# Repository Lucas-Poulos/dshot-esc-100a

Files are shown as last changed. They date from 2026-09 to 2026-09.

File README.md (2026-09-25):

# dshot-esc-100a

A 12 V, 100 A three-phase **all-N-channel** motor driver for a high-power
drone motor, controllable over **DShot150/300/600/1200**.

| | |
|---|---|
| Battery | 3S LiPo, 9.0–12.6 V (operating range 6–16 V) |
| Continuous | **100 A** (~1.2 kW) |
| Burst | **150 A** for 10 s |
| Bridge | 6 switch positions × **2 paralleled N-channel MOSFETs = 12 total** |
| Gate driver | **DRV8323R** (RS or RH — one footprint, both variants) |
| Controller | **STM32G071CBT6** running **AM32** |
| Control | DShot150/300/600/1200, bidirectional, + ESC telemetry |
| Efficiency | ~98.5 % at 100 A (≈19 W dissipated) |

**Status: schematic complete and ERC-clean (160 components). PCB floorplanned
and DRC-clean — 80 × 68 mm, 4 layers, 2 oz outer. Routing not started.**

---

## Why all N-channel, and how the high side is driven

A P-channel high-side switch is the easy way to build a bridge and the
wrong way here — P-channel parts with usable R_DS(on) at 100 A don't exist
in a sane package. Both rails are N-channel, so the high-side gate has to
be driven above the battery rail.

The DRV8323R does that with an on-chip **charge pump**, not a bootstrap
capacitor. A bootstrap cap must be refreshed by pulling the phase node
low, which caps duty cycle below 100 %. A charge pump holds the gate up
indefinitely, so the high-side FET stays fully enhanced at **100 % duty** —
exactly the regime "drive it hard" lives in.

## Shoot-through: four independent layers

Shoot-through at 12 V into 2 × 0.43 mΩ is roughly **14 kA**, limited only
by parasitics. It destroys the bridge in microseconds and no fuse is fast
enough. So it's prevented four times over, and no single layer is trusted:

| Layer | Mechanism | Independent of |
|---|---|---|
| 1 | TIM1 hardware dead-time generator, **625 ns** | firmware timing bugs |
| 2 | DRV8323R cross-conduction lockout + 100 ns | the MCU entirely |
| 3 | 6 × SN74LVC1G97 combinational interlock | MCU *and* driver |
| 4 | Gate-source pulldowns + per-FET series gate resistors | everything active |
| 0 | `nFAULT` → `TIM1_BKIN` kills all 6 outputs in hardware | firmware latency |

The dead-time budget works out **negative** under nominal conditions —
because sink current is set 3.5× source current, the outgoing FET is
already off before the incoming one conducts. The 625 ns is therefore pure
margin against V_th spread, tempco, and gate ringing. Full derivation from
the FET's measured gate charge: **[`docs/shoot-through.md`](docs/shoot-through.md)**.

## Documentation

| Document | What's in it |
|---|---|
| [`docs/architecture.md`](docs/architecture.md) | topology, block diagram, sheet map, design decisions |
| [`docs/shoot-through.md`](docs/shoot-through.md) | the four layers, dead-time budget, DTG encoding |
| [`docs/power-budget.md`](docs/power-budget.md) | conduction/switching/shunt losses, thermals, why 2 FETs not 3 |
| [`docs/pinout.md`](docs/pinout.md) | full 48-pin MCU map + AM32 hardware group |
| [`docs/gate-driver-config.md`](docs/gate-driver-config.md) | RH vs RS dual build, every register value derived |
| [`docs/layout.md`](docs/layout.md) | stackup, floorplan, and the routing rules — **read before routing** |
| [`docs/references.md`](docs/references.md) | every datasheet and firmware source used |
| [`firmware/README.md`](firmware/README.md) | AM32 target, SPI init, flashing, **bring-up order** |
| [`manufacturing/BOM.md`](manufacturing/BOM.md) | generated from the netlist, real LCSC numbers |
| [`manufacturing/dshot-esc-100a/ISSUES.md`](manufacturing/dshot-esc-100a/ISSUES.md) | 12 open items — read before fabricating |

## Repository layout

```
design/          GENERATED KiCad 10 project — schematic never saved from the GUI
  01_power_in  02_gate_driver  03_power_stage
  04_mcu       05_sense        06_protection
  lib/         DRV8323R + STM32G071CBTx symbols
scripts/        the source of truth for everything in design/
  gen_custom_symbols.py  gen_project.py  wire_sheets.py
  gen_footprints.py      gen_pcb.py      verify_project.py
  gen_bom.py             calc_*.py
  kicad_sch.py           kicad_symlib.py
docs/           design documentation
firmware/       AM32 target + DRV8323RS SPI driver
datasheets/     22 PDFs, synced from LCSC
manufacturing/  BOM, schematic PDF, issue tracker
```

## Reproducing the design

```bash
pgrep -fil kicad                            # must be empty first
python3 scripts/gen_custom_symbols.py       # symbol library
python3 scripts/gen_project.py --verify     # refuses to write if broken
python3 scripts/gen_project.py              # sheets + placement + wiring
python3 scripts/gen_bom.py
python3 scripts/verify_project.py           # the real gate
```

The calculations behind the docs are runnable, not asserted:

```bash
python3 scripts/calc_deadtime.py    # DTG table + dead-time budget
python3 scripts/calc_power.py       # loss and thermal budget
```

## Before you build one

Read [`ISSUES.md`](manufacturing/dshot-esc-100a/ISSUES.md). 11 open, 2
resolved. The ones that still matter most:

- **ESC-001** — the input ripple budget (~50 A RMS) isn't closed.
- **ESC-005** — the shunt needs a Kelvin sense tap in layout; at 0.25 mΩ
  a few mΩ of shared trace is a large error.
- **ESC-012** — 19 W is **not** passively coolable; this design assumes
  forced air.
- **ESC-007** — the buck feedback divider is unverified. Check it before
  first power-on or the MCU may sit outside its supply range.

And follow the bring-up order in `firmware/README.md`. Do not put a motor
on this board first.

## Licence

Hardware: CERN-OHL-S v2. Firmware snippets: MIT, matching AM32.

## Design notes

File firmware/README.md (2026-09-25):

# Firmware — AM32 on this board

This board runs [AM32](https://github.com/am32-firmware/AM32), which is what
makes it DShot-compatible: DShot150/300/600/1200, bidirectional DShot,
and ESC telemetry, all already implemented and field-proven.

Two things are needed on top of stock AM32:

1. **A target definition** (`am32_target.h`) — mechanical, just constants.
2. **A DRV8323RS SPI init** (`drv8323.c`) — AM32 has no SPI gate-driver
   driver at all. Only needed for the **RS** build; an **RH** build runs
   stock AM32 unmodified.

## 1. Target definition

Add the block in `am32_target.h` to AM32's `Inc/targets.h`, and add
`DSHOT_ESC_100A` to the Makefile target list.

Key choices and why:

| Define | Value | Reason |
|---|---|---|
| `HARDWARE_GROUP_G0_A` | — | matches this board's TIM1/COMP2/TIM3 pin map exactly |
| `NO_PA11_PA12_REMAP` | set | **critical.** On the 48-pin G071, PA9/PA10 are dedicated pins 29/32. AM32 remaps PA11/PA12 onto them by default, which is right for 28/32-pin parts and wrong here. Without this the three high-side PWM outputs drive unbonded pads and the motor never spins. The shipping `AIKON_04_G071` target does the same thing. |
| `DEAD_TIME 40` | 625 ns | raw TIM1 `BDTR.DTG`, not nanoseconds. Derived in `docs/shoot-through.md`. |
| `MILLIVOLT_PER_AMP 10` | — | 0.25 mOhm shunt x 40 V/V CSA gain |
| `TARGET_VOLTAGE_DIVIDER 110` | — | 100 k / 10 k = 11:1 (see ESC-011) |

## 2. DRV8323RS SPI init

`drv8323.c` writes the five control registers derived in
`docs/gate-driver-config.md`. It **bit-bangs** SPI rather than using SPI2.

That is a deliberate choice, not a shortcut:

- It is a one-shot transaction at boot plus optional fault polling. There
  is no throughput requirement whatsoever.
- It removes all dependence on the STM32G0 alternate-function table for
  PB10/PB11/PB2, which has **not** been verified against DS12232 (ESC-002).
  Wrong AF number costs a board spin; bit-banging cannot be wrong.
- AM32 has no SPI infrastructure, so hardware SPI would mean adding clock
  enables and init to shared code for zero benefit.

Hardware SPI2 stays available as a later optimisation — the pins were
chosen to be SPI2-capable.

### Call site

In `Src/main.c`, after `initCorePeripherals()` and before the motor is
enabled:

```c
#ifdef USE_DRV8323
    drv8323_init();
#endif
```

### Fault handling

`nFAULT` lands on **PB12 / TIM1_BKIN**. To get the hardware break path,
change AM32's `MX_TIM1_Init()`:

```c
    TIM_BDTRInitStruct.BreakState    = LL_TIM_BREAK_ENABLE;   /* was DISABLE */
    TIM_BDTRInitStruct.BreakPolarity = LL_TIM_BREAK_POLARITY_LOW;
```

With break enabled, a driver fault forces all six outputs inactive in
hardware within one timer clock, with no interrupt and no firmware in the
path. Handling `nFAULT` as a GPIO interrupt instead — which is what most
ESC designs do — costs roughly a microsecond, and a microsecond of
shoot-through at 12 V has already destroyed the bridge.

> This depends on PB12 actually carrying TIM1_BKIN on this package, which
> is **ESC-003 and still unverified**. Until it is confirmed, treat the
> break path as designed-in but unproven, and keep an EXTI fallback.

## Flashing

SWD on `J401` (2x05, 1.27 mm, ARM Cortex Debug pinout) with an ST-LINK:

```bash
# 1. bootloader (once per board)
#    pick the G071 bootloader whose input pin is PB4
# 2. main firmware
make DSHOT_ESC_100A
```

After the bootloader is in, further updates go over the signal wire from a
Betaflight FC or a one-wire USB-serial adapter — no ST-LINK needed.

## Bring-up order

Do not put a motor on this board first.

1. No FETs populated. Confirm 3V3 from the buck, confirm SWD, flash.
2. Still no FETs. Scope `INHx`/`INLx` at the **driver side** of the
   interlock and confirm no overlap, at low and high throttle.
3. Populate FETs. Bench supply **current-limited to 2 A**, no motor.
   Command low throttle; the supply current should stay in the mA range.
   Any jump to the limit is shoot-through — stop.
4. Small motor, no propeller, current-limited supply.
5. Only then the real motor, and only then a propeller.

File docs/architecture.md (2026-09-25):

# Architecture — 12 V / 100 A All-N-Channel Three-Phase Motor Driver

## What this board is

A single-motor brushless ESC (electronic speed controller) for a high-power
12 V drone motor. Six switch positions, each built from **two paralleled
N-channel MOSFETs** (12 FETs total), driven by a **DRV8323R smart gate
driver** with external FETs, commanded by an **STM32G071** running **AM32**
open-source firmware so the board speaks **DShot150/300/600/1200**.

| Parameter | Value | Notes |
|---|---|---|
| Battery | 3S LiPo, 9.0–12.6 V | nominal 11.1 V |
| Operating range | 6–16 V | driver min 6 V; 4S (16.8 V) tolerated |
| Absolute max (silicon) | 40 V FET / 60 V driver | >3x margin on switch-node ringing |
| Continuous current | **100 A** | ~1.2 kW at 12 V |
| Burst current | **150 A**, 10 s | thermally limited, not silicon limited |
| Bridge | 6 positions x 2 FETs = **12 N-channel** | high side AND low side are NMOS |
| PWM frequency | 24 kHz default, 48 kHz option | set in AM32 target |
| Control input | DShot150/300/600/1200, bidirectional | plus telemetry UART |

## Why all-N-channel, and what makes the high side work

A P-channel high-side switch is the easy way to build a bridge, and it is
the wrong way here: P-channel parts with usable R_DS(on) at these currents
do not exist in a sane package. Both rails are N-channel, which means the
high-side gate has to be driven *above* the battery rail.

The DRV8323R solves this with an on-chip **doubler charge pump** rather than
a bootstrap capacitor. That distinction matters for this application:

- A bootstrap cap must be refreshed by pulling the phase node low, so it
  cannot hold the high-side FET on indefinitely — duty cycle is capped
  somewhere below 100%.
- A charge pump holds the gate up forever, so the DRV8323R **supports 100%
  duty cycle**. At full throttle the high-side FET stays fully enhanced,
  which is exactly the regime "drive it very hard" lives in.

The low side is fed from an on-chip low-side linear regulator (VGLS), so
both rails get a clean ~10 V V_GS independent of battery sag.

## Block diagram

```
 XT90 / 8AWG        ┌──────────────── VBAT (12 V) ─────────────────┐
   +12 V ──┬────────┤                                              │
           │    bulk caps                                          │
          GND   3x 330uF polymer        ┌─────────────────┐        │
                + 24x 10uF MLCC         │   DRV8323R      │        │
                                        │  smart gate drv │        │
  ┌──────────────┐   6x PWM   ┌─────────┤  - charge pump  │        │
  │ STM32G071CBU6│───────────▶│interlock│  - VGLS LDO     │        │
  │   (AM32)     │  INHx/INLx │ 6x AND  │  - dead time    │        │
  │              │◀───nFAULT──┤ (74LVC) │  - VDS OCP      │        │
  │ TIM1 + dead  │            └─────────┤  - 3x CSA       │        │
  │ time + BKIN  │◀──SPI (RS variant)───┤  - 600mA buck   │──3V3───┤
  └──────┬───────┘                      └────┬────────────┘        │
         │  COMP2 BEMF                       │ GHx/SHx/GLx         │
         │  + virtual neutral                ▼                     │
         │                     ┌──────────────────────────┐        │
         └─────────────────────┤  12x NMOS, 2 per switch  │        │
    DShot in (PB4) ────────────┤  40 V, 0.85 mOhm         │        │
                               └──────────┬───────────────┘        │
                                          │ A  B  C                │
                                    0.25 mOhm shunt ───────────────┘
                                          │
                                       ┌──▼──┐
                                       │MOTOR│
                                       └─────┘
```

## Sheet map

| Sheet | Block | Key parts |
|---|---|---|
| 01 | Power input & bulk | XT90 pads, reverse-polarity FET, bulk cap bank, TVS |
| 02 | Gate driver | U201 DRV8323R + charge pump / VGLS / buck passives |
| 03 | Power stage | 12x Q3xx MOSFETs, gate networks, shunt, phase pads |
| 04 | MCU | U401 STM32G071CBU6, SWD, DShot input, telemetry |
| 05 | Sense | BEMF dividers, virtual neutral, VBAT divider, NTC |
| 06 | Protection | 6x interlock gates, nFAULT -> TIM1_BKIN, pulldowns |

## Design decisions and the reasoning

**Two FETs per switch, not three.** Two halves conduction loss versus one
while keeping per-position gate charge at ~206 nC, which the DRV8323R charge
pump can still refresh at 48 kHz with margin (see `power-budget.md`). Three
would push the charge pump to its limit and buy less than the first
doubling did.

**40 V FETs on a 12 V bus.** 3S peaks at 12.6 V, but a hard-switched
150 A bridge rings. Parasitic loop inductance of even 5 nH with a 150 A
edge at 100 ns gives V = L·di/dt = 7.5 V of overshoot on top of the rail,
and real layouts do worse. 40 V leaves the part operating at under a third
of its rating.

**Single low-side shunt, three CSAs wired for it.** All three low-side
sources tie to one node; the shunt sits between that node and PGND. CSA A
reads total bus current for AM32 telemetry, CSA B and C are shorted to
PGND. Per-phase VDS overcurrent still works because SHA/SHB/SHC remain
independent. Three separate shunts would buy per-phase FOC current and cost
three times the shunt dissipation — deferred, not designed out.

**Dual-build gate driver.** DRV8323RS (SPI) and DRV8323RH (resistor) are
the same VQFN-48 7x7 pinout with the config pins repurposed. The board
carries both the resistor network and the SPI routing; assembly picks one.
See `docs/gate-driver-config.md`.

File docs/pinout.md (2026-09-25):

# MCU Pinout — STM32G071CBT6 (LQFP-48, 7x7 mm)

## Why this part

AM32 supports the STM32G071. The 48-pin variant is chosen over the more
common 32-pin because it is the only one that frees **PB12 (TIM1_BKIN)**,
which is what makes the hardware fault-break path in `shoot-through.md`
possible, and it leaves a clean SPI bus for the DRV8323RS. It is also
better stocked and *cheaper* than the 32-pin part (LCSC C432212, 3813 in
stock, $2.18 vs C529350 at 424 / $2.54).

Pin numbers below are read from KiCad's own vetted symbol, not transcribed
by hand. KiCad 10 has no `STM32G071CBTx` symbol, but it has
**`STM32G081CBTx`** — the G081CB is the same die and the same package
bonding as the G071CB, differing only by the AES accelerator, and ST
documents both in a single datasheet (**DS12232**). `gen_custom_symbols.py`
copies that symbol into the project library under the correct name.

## AM32 hardware group

`HARDWARE_GROUP_G0_A` + `NO_PA11_PA12_REMAP`.

On the 48-pin package PA9 and PA10 exist as **dedicated** pins 29 and 32,
while pins 33 and 34 are the PA11/PA12 pads that *can* be remapped to
PA9/PA10. AM32 remaps by default (`LL_SYSCFG_EnablePinRemap` in
`Mcu/g071/Src/peripherals.c`), which is right for 28/32-pin parts where
PA9/PA10 are not bonded. Here it is wrong, so the target defines
`NO_PA11_PA12_REMAP` and we wire the dedicated pins 29/32. The shipping
`AIKON_04_G071` target does exactly this, so the path is proven.

## Pin assignment

| Pin | Port | Net | Function |
|---:|---|---|---|
| 1 | PC13 | — | spare |
| 2 | PC14 | — | spare (OSC32_IN) |
| 3 | PC15 | — | spare (OSC32_OUT) |
| 4 | VBAT | +3V3 | tied to VDD |
| 5 | VREF+ | +3V3A | via ferrite + 1 uF \|\| 100 nF |
| 6 | VDD | +3V3 | 100 nF + 4.7 uF |
| 7 | VSS | GND | |
| 8 | PF0 | — | spare |
| 9 | PF1 | — | spare |
| 10 | PF2 | NRST | 100 nF to GND, 10 k pull-up |
| 11 | PA0 | `DRV_nSCS` | SPI chip select (plain GPIO) |
| 12 | PA1 | `ADC_TEMP` | **ADC_IN1** — board temperature |
| 13 | PA2 | `BEMF_C` | **COMP2_INM (IO3)** — phase C back-EMF |
| 14 | PA3 | `V_NEUTRAL` | **COMP2_INP (IO3)** — virtual star point |
| 15 | PA4 | `ADC_BUSV` | **ADC_IN4** — bus voltage divider |
| 16 | PA5 | `LED_DATA` | WS2812 strip (optional) |
| 17 | PA6 | `ADC_CURRENT` | **ADC_IN6** — from DRV8323 SOA |
| 18 | PA7 | `INLC` | **TIM1_CH1N** — phase C low |
| 19 | PB0 | `INLB` | **TIM1_CH2N** — phase B low |
| 20 | PB1 | `INLA` | **TIM1_CH3N** — phase A low |
| 21 | PB2 | `DRV_SDO` | SPI MISO (SPI2_MISO capable) |
| 22 | PB10 | `DRV_SCLK` | SPI SCK (SPI2_SCK capable) |
| 23 | PB11 | `DRV_SDI` | SPI MOSI (SPI2_MOSI capable) |
| 24 | PB12 | `DRV_nFAULT` | **TIM1_BKIN** + EXTI — hardware break |
| 25 | PB13 | `DRV_ENABLE` | GPIO out, 10 k pulldown |
| 26 | PB14 | `DRV_CAL` | GPIO out — CSA auto-calibrate |
| 27 | PB15 | — | spare |
| 28 | PA8 | `INHC` | **TIM1_CH1** — phase C high |
| 29 | PA9 | `INHB` | **TIM1_CH2** — phase B high (dedicated pin) |
| 30 | PC6 | `LED_STATUS` | status LED |
| 31 | PC7 | — | spare |
| 32 | PA10 | `INHA` | **TIM1_CH3** — phase A high (dedicated pin) |
| 33 | PA11 | — | **no connect** (remap disabled) |
| 34 | PA12 | — | **no connect** (remap disabled) |
| 35 | PA13 | `SWDIO` | debug |
| 36 | PA14 | `SWCLK` | debug (also PA14-BOOT0) |
| 37 | PA15 | — | spare |
| 38–41 | PD0–PD3 | — | spare |
| 42 | PB3 | `BEMF_B` | **COMP2_INM (IO1)** — phase B back-EMF |
| 43 | PB4 | `DSHOT_IN` | **TIM3_CH1 + DMA1_CH1** — DShot input |
| 44 | PB5 | — | spare |
| 45 | PB6 | `TELEM` | **USART1 (AF0)** — one-wire telemetry |
| 46 | PB7 | `BEMF_A` | **COMP2_INM (IO2)** — phase A back-EMF |
| 47 | PB8 | — | spare |
| 48 | PB9 | — | spare |

## Sensorless commutation

AM32 runs one comparator (COMP2) and multiplexes its **inverting** input
between the three phase dividers, while the **non-inverting** input sits on
a fixed virtual neutral. Verified against
`Mcu/g071/Src/peripherals.c`, which states the mapping in a comment:

```
PA2   ------> COMP2_INM
PA3   ------> COMP2_INP
```

and `Inc/targets.h`:

```c
#define PHASE_A_COMP LL_COMP_INPUT_MINUS_IO2 // pb7
#define PHASE_B_COMP LL_COMP_INPUT_MINUS_IO1 // pb3
#define PHASE_C_COMP LL_COMP_INPUT_MINUS_IO3 // pa2
```

The virtual neutral is three equal resistors from phase A/B/C tied to a
common node — it synthesises the motor's star point, which is not brought
out on a delta or unterminated wye motor. See sheet 05.

## Open items

> **ESC-002 — SPI alternate-function numbers unverified.** PB10/PB11/PB2
> are the correct *pins* for SPI2 on STM32G0, but the AF index for each
> has not been read out of DS12232 Table 13. This is deliberately not
> load-bearing: AM32 has no SPI driver, so the DRV8323RS configuration
> transfer is **bit-banged** on these pins as plain GPIO. Hardware SPI2 is
> an optimisation to enable later, only after the AF table is checked.

> **ESC-003 — TIM1_BKIN AF on PB12 unverified.** Same situation. The break
> input is a genuine hardware feature and must be confirmed against
> DS12232 before the fault-break path in `shoot-through.md` can be claimed
> as working. If PB12 turns out not to carry TIM1_BKIN, the fallback is
> EXTI on the same pin, which costs interrupt latency (~1 us) instead of
> being instantaneous.

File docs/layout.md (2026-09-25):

# PCB Layout — Stackup, Floorplan, Routing Rules

**Board: 80 × 68 mm, 4 layers, 1.6 mm, 2 oz outer copper.**
Placement is generated by `scripts/gen_pcb.py` and is **DRC-clean at
0 violations** (382 unconnected items is expected — nothing is routed yet).

---

## The one number that matters

Everything else on this board is ordinary. The commutation loop is not:

```
bulk ceramic → high-side FET → phase node → low-side FET → shunt → PGND → ceramic
```

At 150 A with 50 ns edges, `di/dt` = **3 A/ns**. Every 1 nH of loop
inductance adds 3 V of overshoot to a 40 V FET already sitting on a
12.6 V rail.

Loop inductance is set by the distance to the **return plane**, not by
how cleverly the FETs are arranged (`L = μ₀·d·l/w`):

| Return path | `d` | `L_loop` | Overshoot | V_DS peak |
|---|---:|---:|---:|---:|
| High side top / low side bottom | 1.60 mm | 4.36 nH | 13.1 V | 25.7 V |
| All FETs top, return on B.Cu | 1.60 mm | 4.36 nH | 13.1 V | 25.7 V |
| All FETs top, In1 at 0.5 mm (stock 4-layer) | 0.50 mm | 1.36 nH | 4.1 V | 16.7 V |
| **All FETs top, In1 at 0.20 mm (this board)** | **0.20 mm** | **0.54 nH** | **1.6 V** | **14.2 V** |

Splitting high-side and low-side across the board is intuitively
appealing and about **8× worse**, because it forces the return current
through the full board thickness. So: all twelve FETs on F.Cu, with an
unbroken ground plane 0.2 mm beneath them.

## Stackup — tell the fab the 0.2 mm is not negotiable

```
F.Cu     2 oz (70 µm)   DC+ pour, 12 FETs, phase pours, ceramics, shunt, driver
   ──── 0.20 mm prepreg ────   ← the whole trick is this number
In1.Cu   1 oz           SOLID PGND. No splits under the bridge, ever.
   ──── 0.97 mm core ────
In2.Cu   1 oz           gate + sense routing, AGND island under the driver
   ──── 0.20 mm prepreg ────
B.Cu     2 oz (70 µm)   phase lanes to the motor pads, logic, thermal copper
```

A house-standard symmetric 4-layer stack (0.5/0.5/0.5) triples the loop
inductance. If the fab substitutes it, the design has lost most of its
margin.

## Floorplan

```
   0                                                              80 mm
 0 ┌──────────────────────────────────────────────────────────────┐
   │ (o)          ╔══════ DC+ pour ══════════════════════════╗    │
   │  J101 ⊙      ║  24 × 10 µF ceramic, 3 rows              ║    │
   │  VBAT+   C101║  ── directly above the high-side drains ─║    │
15 │  J102 ⊙  C102║  Q301 Q302 │ Q305 Q306 │ Q309 Q310  ← HS ║    │
   │  VBAT-   C103║  ═══ PHASE_A ═══ PHASE_B ═══ PHASE_C ════║    │
30 │  D101 TVS    ║  Q303 Q304 │ Q307 Q308 │ Q311 Q312  ← LS ║    │
   │              ║  RS301..RS304  0.25 mΩ shunt             ║    │
40 │              ╚══════════════════════════════════════════╝    │
   │   gate nets  C201..C208      U201 DRV8323R     L201  R201-211│
55 │              ┌──────────┬──────────┬──────────┐              │
   │              │ PHASE_A  │ PHASE_B  │ PHASE_C  │  lanes on    │
   │ (o)          ⊙ J301     ⊙ J302     ⊙ J303     │  B.Cu        │
68 └──────────────────────────────────────────────────────────────┘
        B.Cu x < 29: MCU, 6 × interlock, headers, decoupling
```

Current flows **down each column**: DC+ → HS drain → HS source → phase →
LS drain → LS source → shunt → PGND. All three columns are identical, so
the three phases commutate the same way. FETs are rotated 90° so the
source/gate edge faces down and the big centre drain pad faces the pour
above it — rotating them the other way makes every phase current double
back on itself and doubles the loop area.

### Layer duties

| Layer | Carries |
|---|---|
| **F.Cu** | DC+ pour, all 12 FETs, phase pours, ceramics, shunt, gate driver, gate networks |
| **In1.Cu** | **Solid PGND.** The return for every commutation loop |
| **In2.Cu** | Gate and sense routing, AGND island under the driver |
| **B.Cu** | Three phase lanes down to the motor terminals, all logic at x < 29, thermal copper |

The three B.Cu phase lanes (x 29.5–38.5, 45.5–54.5, 61.5–70.5, y 22–63)
are kept clear of every part. That is a *routing convenience*, not an
inductance requirement — the motor lead is in series with a 10–100 µH
winding, so its own inductance is irrelevant.

---

## Routing rules, in priority order

1. **Never split In1.Cu under the bridge.** A slot in the return plane
   forces the return current around it and undoes the entire stackup
   argument. No signals on In1 in the bridge area, at all.
2. **Ceramics first, then everything else.** Each 10 µF must reach the
   DC+ pour and drop to In1 through its own via pair, as short as
   possible. These are the loop's high-frequency source; the
   electrolytics are far too slow to participate.
3. **Phase pours: wide enough for 100 A, and no wider.** The phase node
   is the board's dv/dt aggressor. 2 oz copper at 100 A with a 20 °C rise
   needs roughly 20 mm width, or fewer mm plus via stitching to B.Cu.
4. **Shunt sense must be Kelvin (ESC-005).** `SPA`/`SNA` tap the shunt
   pads directly, never the power pour. At 0.25 mΩ, a few mΩ of shared
   trace is a large fractional error.
5. **Gate loops tight and equal.** Route each `GHx`/`GLx` with its return
   (`SHx` for high side, `SHUNT_P` for low side) as a pair. Length
   *mismatch* between phases is not critical — 14 mm of trace is ~84 ps,
   against 625 ns of dead time — but loop *area* is.
6. **Thermal vias under U201.** The stock `_ThermalVias` footprint was
   deliberately **not** used: it embeds 0.2 mm vias and this board is
   2 oz, where 0.3 mm is the realistic fab minimum. Place a 0.3 mm via
   array by hand on the exposed pad.
7. **Keep the phase lanes off the logic.** Already true by placement;
   preserve it when routing.

## Thermals

~19 W at 100 A continuous into 80 × 68 mm is about **0.35 W/cm²** —
better than the 1.1 W/cm² the earlier 50 × 35 mm estimate in
`power-budget.md` assumed, but still **not passively coolable**. The
design assumes propwash or forced air (ESC-012). Bench testing at 100 A
needs a fan.

The shunt is the hottest discrete at 2.5 W; give it copper on both outer
layers and stitch generously.

## Reproducing

```bash
pgrep -fil kicad        # must be empty — the script edits the .kicad_pcb

/Applications/KiCad/KiCad.app/Contents/Frameworks/Python.framework/\
Versions/Current/bin/python3 scripts/gen_pcb.py

kicad-cli pcb drc --output /tmp/drc.rpt --severity-error \
    design/dshot-esc-100a.kicad_pcb        # currently 0 violations
```

`gen_pcb.py` **edits the board in place** so the `(path ...)` linkage from
"Update PCB from Schematic" survives. It also clears and re-adds its own
zones each run — `pcbnew.SaveBoard()` rewrites every UUID, so deduping by
UUID silently accumulated 14 stacked pours before this was caught.

> Once hand-routing starts, stop running `gen_pcb.py`: it re-places every
> footprint. Tracks and hand-drawn zones would survive, but the placement
> they were routed to would not.

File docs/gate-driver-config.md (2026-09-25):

# DRV8323R Configuration — RH and RS Builds

The board is laid out for **both** DRV8323R variants. They are the same
VQFN-48 RGZ package with the same pinout; per datasheet SLVSDJ3D Table 6-4,
**only pins 29-32 differ**:

| Pin | DRV8323**RH** (hardware) | DRV8323**RS** (SPI) |
|---:|---|---|
| 29 | `MODE` | `SDO` |
| 30 | `IDRIVE` | `SDI` |
| 31 | `VDS` | `SCLK` |
| 32 | `GAIN` | `nSCS` |

| | RH | RS |
|---|---|---|
| LCSC | C543035 | C2653553 |
| Stock / price | 2338 / $2.39 | 67 / $4.29 |
| Configured by | resistors R203-R206 | MCU, over SPI |
| Firmware needed | **none** — stock AM32 runs | `drv8323.c` init (supplied) |
| Retuning | swap resistors | change a constant, reflash |

> **Populate exactly one set.** For an RH build fit R203-R206 and leave the
> MCU's SPI pins as inputs. For an RS build **do not fit R203-R206** — a
> 10 k resistor to ground on a live SPI line is a fight the MCU wins, but
> it corrupts logic levels and wastes current. R207 (SDO pull-up) is fitted
> only for RS; SDO is open-drain.

---

## RS build — register values

Derived from SLVSDJ3D Tables 8-15 through 8-19, and from the FET's own
measured gate charge (see `docs/shoot-through.md`). Implemented in
`firmware/drv8323.c`.

### 0x02 Driver Control — `0x080`

| Field | Bits | Value | Why |
|---|---|---|---|
| `PWM_MODE` | 6-5 | `00b` | **6x PWM** — independent high/low per phase, which is what AM32's TIM1 complementary outputs produce |
| `OTW_REP` | 7 | `1b` | report overtemperature warning on `nFAULT` so the break path sees thermal trouble early |
| `DIS_CPUV` | 9 | `0b` | charge-pump undervoltage fault **enabled** |
| `DIS_GDF` | 8 | `0b` | gate-drive fault **enabled** |

### 0x03 Gate Drive HS — `0x39C`

| Field | Bits | Code | Value |
|---|---|---|---|
| `LOCK` | 10-8 | `011b` | unlocked |
| `IDRIVEP_HS` | 7-4 | `1001b` | **330 mA** source |
| `IDRIVEN_HS` | 3-0 | `1100b` | **1140 mA** sink |

### 0x04 Gate Drive LS — `0x79C`

`CBC = 1b`, `TDRIVE = 11b` (4000 ns peak-current window), and the same
`IDRIVEP_LS = 1001b` / `IDRIVEN_LS = 1100b` as the high side.

**Why sink 3.5x harder than source.** Qgd is 12.4 nC per FET, so 24.8 nC
per position. SLVSDJ3D Eq. 11/12 give `IDRIVEP > Qgd/t_r = 248 mA` for a
100 ns rise and `IDRIVEN > Qgd/t_f = 496 mA` for a 50 ns fall. Setting sink
well above that minimum makes turn-off finish before turn-on starts, which
is what drives the dead-time budget negative under nominal conditions.

### 0x05 OCP Control — `0x151`

| Field | Bits | Code | Value |
|---|---|---|---|
| `TRETRY` | 10 | `0b` | 4 ms retry |
| `DEAD_TIME` | 9-8 | `01b` | **100 ns** — a floor beneath TIM1's 625 ns, not an addition to it |
| `OCP_MODE` | 7-6 | `01b` | automatic retry |
| `OCP_DEG` | 5-4 | `01b` | 4 us deglitch |
| `VDS_LVL` | 3-0 | `0001b` | **0.13 V** |

`VDS_LVL` sizing, per SLVSDJ3D Eq. 17 (`V_DS_OCP > I_max * R_DS(on)max`):

```
R_DS(on) hot   = 0.85 mOhm * 1.5      = 1.28 mOhm   (per FET, 125 C)
R per position = 1.28 / 2             = 0.64 mOhm   (two in parallel)
trip current   = 0.13 V / 0.64 mOhm   = 203 A  hot
                 0.13 V / 0.425 mOhm  = 306 A  cold
```

203 A sits above the 150 A burst rating with margin and still catches a
phase-to-phase short long before the FETs do. Raising it to `0010b`
(0.2 V) would push the hot trip to 312 A, which protects almost nothing.

### 0x06 CSA Control — `0x0C3`

| Field | Bits | Code | Value |
|---|---|---|---|
| `CSA_FET` | 10 | `0b` | positive input is `SPx` |
| `VREF_DIV` | 9 | `0b` | **unidirectional** — see below |
| `LS_REF` | 8 | `0b` | low-side VDS measured `SHx` to `SPx` |
| `CSA_GAIN` | 7-6 | `11b` | **40 V/V** |
| `SEN_LVL` | 1-0 | `11b` | 1 V (effectively unused, see below) |

**Unidirectional, not bidirectional.** The default `VREF_DIV = 1b` puts
zero current at VREF/2 = 1.65 V, and AM32 expects a sensor that reads ~0 V
at zero current (`CURRENT_OFFSET` is in millivolts and every shipping
target sets it near 0). Unidirectional also doubles the usable span. The
cost is that regenerative/braking current is no longer measurable —
acceptable for telemetry, and the reason per-phase FOC is listed as a
future change rather than a present capability.

**Scaling with 40 V/V:**

```
R_shunt = 0.25 mOhm  ->  10 mV/A at the ADC
   100 A -> 1.00 V        150 A -> 1.50 V
linear range 0.25 V .. VREF-0.25 V = 3.05 V  ->  saturates at ~305 A
```

So AM32 gets `MILLIVOLT_PER_AMP 10`.

`SEN_LVL` (the shunt overcurrent comparator) would need 1 V across
0.25 mOhm — 4000 A. It can never trip and is left at its default; VDS
overcurrent is the protection that actually does the work here.

---

## RH build — resistor values

`IDRIVE`, `VDS`, `MODE` and `GAIN` are multi-level inputs: the pin is read
as one of 4 or 7 levels set by a resistor to GND (or a tie to GND/VCC).
**The level tables live in SLVSDJ3D Section 8.5 and have not yet been
transcribed** — see issue **ESC-010**. Populating R203-R206 at the
placeholder 10 k shown on sheet 02 will *not* give the settings tabulated
above.

Targets to hit, once the tables are read:

| Pin | Target |
|---|---|
| `MODE` | 6x PWM |
| `IDRIVE` | ~330 mA source / ~1140 mA sink |
| `VDS` | 0.13 V |
| `GAIN` | 40 V/V |

Note the RH part cannot set source and sink independently — one `IDRIVE`
pin sets both. The asymmetry the dead-time budget relies on is therefore
**an RS-only property**. An RH build still has 625 ns of TIM1 dead time
plus the driver's own 100 ns plus the discrete interlock, so it is safe;
it just has less margin than the RS build. This is the strongest technical
argument for populating RS.

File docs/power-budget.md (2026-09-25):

# Power Budget and Thermal Analysis

All numbers are for the worst case the board is specified to: **100 A
continuous, 12.6 V bus, 24 kHz PWM, 120-degree trapezoidal commutation**,
which is what AM32 does. Burst figures use 150 A.

Every calculation here is reproducible with `scripts/calc_power.py`.

## 1. Conduction loss

In 6-step drive two phases conduct and one floats at any instant. Each
switch position therefore conducts for 120 degrees of the 360-degree
electrical cycle — a duty of 1/3 — and carries the full phase current while
it does.

```
I_rms(per position) = I_phase * sqrt(1/3) = 100 * 0.5774 = 57.7 A
I_rms(per FET)      = 57.7 / 2            = 28.9 A      (2 in parallel)
```

R_DS(on) rises with junction temperature. The selected FET is 0.85 mOhm max
at V_GS = 10 V, 25 C; the normalised curve gives roughly 1.5x at 125 C:

```
R_hot        = 0.85 mOhm * 1.5 = 1.28 mOhm
P_cond/FET   = 28.9^2 * 1.28e-3 = 1.07 W
P_cond total = 1.07 * 12         = 12.8 W
```

At 150 A burst this scales as I^2: **28.8 W**.

## 2. Switching loss

AM32 PWMs the high-side switch and runs synchronous rectification on the
low side, so one hard transition pair per PWM period per active position.

```
E_sw  = 0.5 * V_bus * I * (t_r + t_f)
      = 0.5 * 12.6 * 100 * (100ns + 100ns)  = 126 uJ
P_sw  = 126e-6 * 24e3                        = 3.0 W   @ 24 kHz
                                             = 6.0 W   @ 48 kHz
```

This is the number that moves most with the IDRIVE setting — faster edges
cut it, at the cost of more ringing and EMI. It is the main reason the
gate drive strength is made adjustable rather than fixed.

## 3. Shunt loss

```
R_shunt = 0.25 mOhm  (4x 1 mOhm 2512 in parallel, 4 W total rating)
P_shunt = 100^2 * 0.25e-3 = 2.5 W     @ 100 A
        = 150^2 * 0.25e-3 = 5.6 W     @ 150 A
```

Four 2512 parts in parallel spread this over ~50 mm^2 of copper. The shunt
is the single hottest discrete component on the board and wants its own
copper pour on both outer layers.

## 4. Gate drive loss

```
Q_g(per position) = 103 nC * 2 = 206 nC
P_gate = Q_g * V_gs * f_pwm * 6 positions
       = 206e-9 * 10 * 24e3 * 6 = 0.30 W
```

Negligible thermally, but it sets the charge pump requirement below.

## 5. Total and thermal

| Source | 100 A cont | 150 A burst |
|---|---:|---:|
| Conduction (12 FETs) | 12.8 W | 28.8 W |
| Switching @24 kHz | 3.0 W | 4.5 W |
| Shunt | 2.5 W | 5.6 W |
| Gate drive | 0.3 W | 0.3 W |
| Driver + MCU + buck | ~0.6 W | ~0.6 W |
| **Total** | **~19 W** | **~40 W** |

19 W into a 4-layer 2 oz board of roughly 50 x 35 mm is about 1.1 W/cm^2.
That is **not** passively coolable at sane temperatures — this board
assumes propwash or forced air, which is the normal condition for an ESC
mounted on a multirotor. Static bench testing at 100 A needs a fan.

The 150 A figure is explicitly a **10-second burst**: 40 W into the same
copper will climb roughly 40 C above the continuous steady state, so it is
bounded by thermal mass, not by dissipation.

## 6. Charge pump headroom (the constraint on paralleling FETs)

DRV8323 datasheet SLVSDJ3D Eq. 9, trapezoidal commutation:

```
I_VCP  >  Q_g * f_PWM
```

`I_VCP` is at least 15 mA at V_VM = 8 V and higher at 12 V. With two FETs
per position:

```
required @ 24 kHz = 206e-9 * 24e3 =  4.9 mA    -> 3.0x margin
required @ 48 kHz = 206e-9 * 48e3 =  9.9 mA    -> 1.5x margin
```

**This is why the design stops at two FETs per position.** A third would
need 14.8 mA at 48 kHz, leaving effectively no margin against the 15 mA
floor, and the failure mode is not graceful — an under-refreshed high-side
gate comes out of full enhancement and the FET cooks.

## 7. Bulk capacitance

Input ripple current for a three-phase inverter peaks near 50% modulation
at roughly `0.5 * I_dc` RMS, so **~50 A RMS at 100 A** — far beyond any
single part.

| Part | Qty | Role |
|---|---:|---|
| 330 uF 25 V polymer, ~4 A ripple | 3 | bulk, ~12 A ripple total |
| 10 uF 25 V X7R 1210 | 24 | distributed across the bridge, ~1.5 A each |
| 100 nF 50 V X7R 0603 | 6 | one per half-bridge, high-frequency loop |

> **Open item ESC-001.** The polymer bank covers ~12 A of the ~50 A ripple
> budget; the MLCC array is doing most of the work and its effective
> capacitance under DC bias must be verified against vendor curves (a
> 10 uF 25 V X7R 1210 typically derates to 5-6 uF at 12 V). The practical
> mitigation used by every ESC in this class is a **low-ESR capacitor at
> the battery connector on short leads**, because lead inductance, not the
> on-board bank, dominates. Document it as a required accessory rather
> than pretending the board alone handles it.

See DRV8323 datasheet section 10.2 "Bulk Capacitance Sizing".

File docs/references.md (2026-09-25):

# References

Every datasheet fact in this repo traces to one of these. Where a figure is
still assumed rather than read, it carries an `ESC-NNN` issue number.

## Primary datasheets (PDFs in `datasheets/`, manifest in `datasheets/manifest.json`)

| Part | Document | Used for |
|---|---|---|
| **DRV8323R** | TI **SLVSDJ3D** rev D, Mar 2022 — *DRV832x 6-to-60-V Three-Phase Smart Gate Driver* | Table 6-4 (48-pin RGZ pinout, RH vs RS), Figure 9-1 (application circuit), Eq. 9-12 (charge-pump and IDRIVE sizing), Eq. 17 (VDS OCP), Tables 8-15…8-19 (register map), §10.2 (bulk capacitance) |
| **STM32G071CB** | ST **DS12232** — *STM32G071x8/xB* | 48-pin LQFP pinout, alternate-function tables (ESC-002, ESC-003) |
| **STM32G0 series** | ST **RM0444** — reference manual | TIM1 `BDTR.DTG` dead-time encoding, COMP2 input routing, SYSCFG PA11/PA12 remap |
| **TPHR8504PL** | Toshiba — *N-channel 40 V 340 A MOSFET, SOP Advance* | Qg = 103 nC, Qgs1 = 25 nC, Qgd = 12.4 nC, R_DS(on) = 0.85 mΩ max @ V_GS = 10 V |
| **SN74LVC1G97** | TI **SCES416N** rev N, Jan 2017 | Table 1 function table, Figure 6 (`In0` = GND ⇒ `Y = In1 AND NOT In2`), SOT-23 pinout |
| **LMR16006X** | TI **SNVSA13** | buck feedback reference and external component sizing (ESC-007) — the DRV8323R's integrated buck is this converter |
| SMBJ20A | LCSC datasheet | 20 V standoff, 24.5 V breakdown, 32.4 V clamp |
| B5819W | LCSC datasheet | 40 V 1 A Schottky, buck catch diode and gate turn-off bypass |

## Firmware

| Source | Used for |
|---|---|
| [am32-firmware/AM32](https://github.com/am32-firmware/AM32) | DShot implementation, target model |
| `Inc/targets.h` | `HARDWARE_GROUP_G0_A` pin map; `AIKON_04_G071` as the precedent for `NO_PA11_PA12_REMAP` on a 48-pin G071 |
| `Mcu/g071/Src/peripherals.c` | clock tree (HSI 16 MHz → PLL ×8 ÷2 = 64 MHz), `TIM1` init (PSC = 0, CKD = DIV1 ⇒ t_DTS = 15.625 ns), `COMP2` GPIO comment (`PA2 → COMP2_INM`, `PA3 → COMP2_INP`), `LL_SYSCFG_EnablePinRemap` default |
| `Mcu/g071/Src/comparator.c` | phase multiplexing onto one comparator, `LL_COMP_INPUT_PLUS_IO3` as the virtual neutral |
| `Mcu/g071/Src/serial_telemetry.c` | USART1 one-wire telemetry on PB6, AF0, 115200 |
| [AM32 wiki](https://wiki.am32.ca/) | supported MCU list, bootloader/flashing procedure |

## KiCad libraries used

| Item | Source | Note |
|---|---|---|
| `Texas_RGZ0048A_VQFN-48-1EP_7x7mm_P0.5mm_EP5.15x5.15mm_ThermalVias` | KiCad `Package_DFN_QFN` | TI's own RGZ land pattern — exactly the DRV8323R package |
| `PQFN-8-EP_6x5mm_P1.27mm_Generic` | KiCad `Package_DFN_QFN` | its own description lists "Toshiba SOP Advance" among the compatible packages |
| `LQFP-48_7x7mm_P0.5mm` | KiCad `Package_QFP` | STM32G071CBT6 |
| `Transistor_FET:Q_NMOS_SSSGD_AvalancheRated` | KiCad stock | S = pads 1-3, G = 4, D = 5 — matches the PQFN-8 land pattern |
| `74xGxx:74LVC1G97` | KiCad stock | `extends 74LVC1G57`; flattened by `kicad_sch.py::_merge_extends` |
| `MCU_ST_STM32G0:STM32G081CBTx` | KiCad stock | copied and renamed to `STM32G071CBTx` — same die and bonding, DS12232 covers both |

## Design references consulted

- TI **SLVA504** / *Architecture for Brushless-DC Gate Drive Systems* — referenced from SLVSDJ3D §5 for the device-family comparison.
- The four-layer shoot-through argument, the paralleled-FET gate-resistor
  rule, and the charge-pump-limits-parallel-count result are derived in
  `docs/shoot-through.md` and `docs/power-budget.md` from the datasheet
  figures above, not taken from a secondary source.

## A note on one source that was wrong

An automated fetch of the SN74LVC1G97 datasheet returned a pin assignment
(`pin 3 = C, pin 5 = B, pin 6 = VCC`) and a configuration table that
contradicted both KiCad's symbol and the device's own logic diagram — its
"inverter" configuration evaluates to a buffer. Reading the PDF directly
gave `In0 = 3, Y = 4, VCC = 5, In2 = 6` and Table 1 above. **The interlock
in `06_protection.kicad_sch` is wired from the PDF, not the summary.**

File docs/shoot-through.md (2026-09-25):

# Shoot-Through Prevention and Dead Time

Shoot-through is the failure where the high-side and low-side FETs of one
half-bridge are on simultaneously, putting the battery across two FETs with
nothing but their R_DS(on) in the path. At 12 V into 2 x 0.43 mOhm that is
roughly **14 kA**, limited only by parasitic inductance. It destroys the
bridge in microseconds and there is no fuse fast enough. So it is prevented
in four independent layers, no one of which is trusted alone.

---

## Layer 1 — TIM1 hardware dead-time generator (primary)

The STM32G071's advanced timer generates the complementary pair in
**hardware**. Firmware writes one duty value; the timer derives `CHxN` as
the inverse with a guaranteed non-overlap window inserted on both edges.
Because it is a hardware state machine, no firmware bug, interrupt storm,
or stalled loop can make the two outputs overlap.

AM32 sets this through `TIM_BDTRInitStruct.DeadTime = DEAD_TIME`, which is
the **raw DTG[7:0] register value**, not nanoseconds. The conversion is
load-bearing and easy to get wrong, so it is derived here rather than
assumed.

AM32 configures the STM32G071 at `HSI 16 MHz -> PLL(M=1, N=8, R=2) = 64 MHz`,
with `SYSCLK` undivided, `TIM1 Prescaler = 0` and
`ClockDivision = DIV1`. Therefore:

```
t_DTS = 1 / 64 MHz = 15.625 ns
```

With `DTG[7:5] = 0xx` (i.e. DEAD_TIME <= 127) the reference manual gives
`DT = DTG[7:0] x t_DTS`:

| `DEAD_TIME` | Dead time | Duty loss @24 kHz | @48 kHz |
|---:|---:|---:|---:|
| 24 | 375 ns | 0.9 % | 1.8 % |
| 32 | 500 ns | 1.2 % | 2.4 % |
| **40** | **625 ns** | **1.5 %** | **3.0 %** |
| 60 | 938 ns | 2.3 % | 4.5 % |
| 80 | 1250 ns | 3.0 % | 6.0 % |

Above 127 the encoding changes slope, which is why the AM32 `DT160` and
`DT210` targets land at 3.0 us and 6.25 us rather than anything linear.

**This board ships `DEAD_TIME 40` (625 ns).** Justification in the budget
below; `scripts/calc_deadtime.py` regenerates this table.

## The dead-time budget

Dead time must outlast the slowest turn-off, because the *outgoing* FET has
to be fully off before the *incoming* one starts conducting:

```
DT_required  >  t_off(outgoing) - t_on_delay(incoming) + margin
```

For two TPHR8504PL in parallel per position, driven at `IDRIVEN` = 1 A
sink and `IDRIVEP` = 300 mA source. Gate-charge figures are read from the
Toshiba TPHR8504PL datasheet Electrical Characteristics table
(VDD ~20 V, V_GS = 10 V, I_D = 50 A): **Qg = 103 nC, Qgs1 = 25 nC,
Qgd = 12.4 nC** per FET.

| Term | Value | Derivation |
|---|---:|---|
| Driver propagation delay, INx -> Gx | ~100 ns | DRV8323 t_PD (ESC-009) |
| Gate discharge, plateau -> off | (206 - 50) nC / 1 A = 156 ns | 2 x (Qg - Qgs1) |
| **t_off total** | **~256 ns** | |
| Driver propagation delay (incoming) | ~100 ns | cancels against the above |
| Gate charge, 0 V -> plateau | 50 nC / 300 mA = 167 ns | 2 x Qgs1 |
| **t_on_delay total** | **~267 ns** | |
| **Net requirement** | **-11 ns** | |

**The net requirement comes out negative**, and that is the real result,
not a rounding artefact. Because `IDRIVEN` is set 3.3x higher than
`IDRIVEP`, the outgoing FET is already off before the incoming one starts
to conduct, even with zero inserted dead time. Under nominal conditions
this bridge cannot cross-conduct.

So the 625 ns is not covering a nominal overlap — there isn't one. It is
margin against everything that is *not* nominal:

- V_th spread across twelve individual FETs,
- Q_g and R_DS(on) drift over a 150 C junction swing,
- two paralleled gates not switching in unison,
- gate-loop ringing momentarily re-crossing V_th.

625 ns costs 1.5 % of duty at 24 kHz. Buying that much insurance against
a failure that destroys twelve MOSFETs is an easy trade, which is why the
number is not tuned down aggressively.

### Gate-drive current, from the same datasheet numbers

DRV8323 datasheet SLVSDJ3D Eq. 11/12 sizes `IDRIVE` from the **Miller**
charge, not total gate charge:

```
Qgd(position) = 2 x 12.4 nC = 24.8 nC
IDRIVEP > Qgd / t_rise = 24.8 nC / 100 ns = 248 mA   -> set 300 mA
IDRIVEN > Qgd / t_fall = 24.8 nC /  50 ns = 496 mA   -> set 1 A
```

The 1 A sink setting is deliberately above the 496 mA minimum: it is what
produces the turn-off/turn-on asymmetry the budget above relies on.

> Reduce toward `DEAD_TIME 24` (375 ns) only on the bench, with a current
> probe on the DC bus watching for the characteristic shoot-through spike
> at each commutation, and only after the FET and gate-drive settings are
> final.

---

## Layer 2 — DRV8323R internal cross-conduction prevention

The DRV8323R, in 6x PWM mode, independently refuses to turn on one side
while the other is still commanded on, and inserts its own programmable
dead time of **50 / 100 / 200 / 400 ns**. This is a property of the gate
driver silicon and holds even if the MCU commands an illegal state.

Set to **100 ns**. It is deliberately *shorter* than the TIM1 value so the
total dead time stays the deterministic, documented 625 ns rather than the
sum of two uncoordinated delays — the driver's setting acts as a floor for
the case where layer 1 is wrong, not as an addition to it.

- **RS variant:** `DEAD_TIME` bits in the Driver Control register, over SPI.
- **RH variant:** resistor on the `DTC` pin.

---

## Layer 3 — Discrete cross-interlock (sheet 06)

Six **SN74LVC1G97** configurable single-gate logic parts (SOT-23-6, LCSC
C128411) sit between the MCU and the driver inputs.

The '1G97 is a 3-input configurable gate. Its function table (datasheet
SCES416N, Table 1) is a 2-to-1 mux with `In2` as the select:

```
  In2 = L  ->  Y = In1
  In2 = H  ->  Y = In0          i.e.  Y = /In2.In1 + In2.In0
```

TI documents the tie-off we want directly, as **Figure 6, "2-Input AND Gate
With One Inverted Input"**: ground `In0`, and the part becomes
`Y = In1 AND NOT In2`. So:

| Gate | pin 1 `In1` | pin 3 `In0` | pin 6 `In2` | pin 4 `Y` |
|---|---|---|---|---|
| high side | `INHx` from MCU | **GND** | `INLx` from MCU | `INHx` to driver |
| low side | `INLx` from MCU | **GND** | `INHx` from MCU | `INLx` to driver |

```
  INHx_drv = INHx AND NOT INLx
  INLx_drv = INLx AND NOT INHx
```

Both outputs cannot be high simultaneously for any input combination -- it
is combinational, so there is no state to corrupt. Propagation delay is
6.3 ns max at 3.3 V and **identical on both paths**, so it adds no skew and
does not eat into the dead-time budget.

**Is this redundant with layer 2? Largely, yes — and it is here anyway,
for two cases layer 2 does not cover:**

1. **Before the driver is configured.** Between power-on and the point
   where firmware asserts `ENABLE` and writes the SPI registers, the
   DRV8323R's PWM mode is not yet known to be 6x. The interlock is true
   from the instant 3V3 comes up.
2. **A wrong SPI write.** In 3x or 1x PWM mode the `INLx` pins change
   meaning entirely (direction / brake rather than low-side command). A
   firmware bug that selects the wrong mode would silently invalidate
   layer 2's interlock assumption. Layer 3 does not care what mode the
   driver is in.

Each gate has a **0 Ohm bypass link** in parallel so the interlock can be
shorted out for characterisation.

---

## Layer 4 — Gate network and fail-safe biasing (sheet 03)

- **10 kOhm gate-source pulldown on every one of the 12 FETs.** An
  undriven gate is a floating gate, and a floating gate on a 12 V bus with
  dv/dt on the drain will turn a FET on through C_gd. This is the single
  most important passive on the power sheet, and it is what makes the board
  safe during power-up, brown-out, and driver reset.
- **Individual 4.7 Ohm series gate resistor per FET**, not per position.
  Two gates tied directly together form a resonant loop through their own
  package inductance and will oscillate at hundreds of MHz. Separate
  resistors de-Q that loop. This is mandatory for paralleled FETs.
- **Anti-parallel diode across the common gate resistor** (one per
  position, 6 total) so turn-off bypasses the resistor while turn-on does
  not. Turn-off becomes faster than turn-on, which *widens* the effective
  dead time — the asymmetry is in the safe direction.
- **10 kOhm pulldown on all six `INHx`/`INLx` driver inputs**, so a
  tri-stated or unpowered MCU commands "off" rather than "undefined".

---

## Layer 0 — nFAULT into TIM1_BKIN (the fast path out)

Not dead-time related, but the same class of protection and worth stating
plainly: the DRV8323R's **`nFAULT`** output goes to **PB12**, which carries
**TIM1_BKIN**. When the driver detects VDS overcurrent, charge-pump
undervoltage, gate-drive fault or overtemperature, it pulls `nFAULT` low
and the timer's break input forces all six PWM outputs to their inactive
state **in hardware, within one timer clock**, with no interrupt, no
firmware, and no latency.

Firmware then sees the break flag and decides whether to latch off or
retry. Routing a fault to a GPIO and handling it in an ISR — which is what
most ESC designs do — costs about a microsecond, and a microsecond of
shoot-through at 12 V is already fatal.

This requires `BDTRInitStruct.BreakState = LL_TIM_BREAK_ENABLE` in the
firmware patch; AM32's stock G071 init has it **disabled**
(`LL_TIM_BREAK_DISABLE`). See `firmware/README.md`.

> **ESC-003** (in `pinout.md`) tracks confirming that PB12 actually carries
> TIM1_BKIN on this package. Until that is read out of DS12232, layer 0 is
> designed-in but not proven.

---

## Summary

| Layer | Mechanism | Covers | Independent of |
|---|---|---|---|
| 1 | TIM1 DTG, 625 ns | normal commutation | firmware timing bugs |
| 2 | DRV8323R interlock + 100 ns | illegal MCU commands | MCU entirely |
| 3 | 6x 74LVC1G97 | pre-config window, wrong SPI mode | MCU and driver |
| 4 | Gate pulldowns + series R | power-up, brown-out, dv/dt | everything active |
| 0 | nFAULT -> TIM1_BKIN | overcurrent, UVLO, thermal | firmware latency |

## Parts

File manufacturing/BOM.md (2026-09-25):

# Bill of materials

Generated from the schematic netlist by `scripts/gen_bom.py` on 2026-09-25. Do not edit by hand -- regenerate.

**43 distinct lines, 160 placements.** The schematic is fully wired and ERC-clean, so these quantities are real rather than provisional.

Prices and stock are deliberately absent -- they go stale within days. Refresh before a BOM lock with the `lcsc` skill.

---

## Sourcing notes

**The gate driver is the line to watch.** The design is laid out for both DRV8323R variants on one footprint -- only pins 29-32 differ (SLVSDJ3D Table 6-4):

| Part | LCSC | Stock | Price | Configured by |
|---|---|---:|---:|---|
| `DRV8323RSRGZT` | C2653553 | ~67 | $4.29 | SPI, from the MCU |
| `DRV8323RHRGZR` | C543035 | ~2338 | $2.39 | resistors R203-R206 |

RS is the default because it can set source and sink gate current independently, which is what produces the turn-off/turn-on asymmetry the dead-time budget relies on. RH cannot -- one pin sets both. An RH build is still safe but has less margin, and its resistor values are **not yet transcribed** (issue ESC-010). See `docs/gate-driver-config.md` before substituting.

Everything else is commodity: no part below has under ~1000 pieces at LCSC, and the FETs, MCU and logic all have multiple sources.

---

## Lines

| Qty | MPN | LCSC | Value | Package | Refs | Sheets |
|----:|-----|---|---|---|---|---|
| 29 | `FRC0603F1002TS` | `C2906982` | 10k | R_0603_1608Metric | R202, R211, R313, R314, ... (+25) | Gate Driver, MCU, Power Stage, Protection, Sense |
| 26 | `GRM32DR71E106KA12L` | `C77100` | 10u | C_1210_3225Metric | C104, C105, C106, C107, ... (+22) | Gate Driver, Power Input |
| 12 | `FRC0805F4R70TS` | `C2933459` | 4.7 | R_0805_2012Metric | R301, R302, R303, R304, ... (+8) | Power Stage |
| 12 | `TPHR8504PL,L1Q(M` | `C5331611` | TPHR8504PL | PQFN-8-EP_6x5mm_P1.27mm_Generic | Q301, Q302, Q303, Q304, ... (+8) | Power Stage |
| 11 | `CC0603KRX7R9BB104` | `C14663` | 100n | C_0603_1608Metric | C203, C401, C402, C501, ... (+7) | Gate Driver, MCU, Protection, Sense |
| 7 | `B5819W SL` | `C8598` | B5819W | D_SOD-123 | D201, D301, D302, D303, D304, D305, D306 | Gate Driver, Power Stage |
| 6 | `RCA030RLF` | `C22356631` | 0 | R_0603_1608Metric | R325, R326, R327, R328, R329, R330 | Power Stage |
| 6 | `RCA030RLF` | `C22356631` | 0R BYP | R_0603_1608Metric | R601, R602, R603, R604, R605, R606 | Protection |
| 6 | `SN74LVC1G97DBVR` | `C128411` | SN74LVC1G97 | SOT-23-6 | U601, U602, U603, U604, U605, U606 | Protection |
| 5 | `FRC0603F1001TS` | `C2907002` | 1k | R_0603_1608Metric | R402, R504, R505, R506, R510 | MCU, Sense |
| 4 | `HoJLR2512-3W-1mR-1%` | `C2903470` | 1m | R_2512_6332Metric | RS301, RS302, RS303, RS304 | Power Stage |
| 3 | `SPZ1EM331F11O00R` | `C160677` | 330u/25V | CP_Radial_D8.0mm_P3.50mm | C101, C102, C103 | Power Input |
| 2 | `0603WAF1003T5E` | `C25803` | 100k | R_0603_1608Metric | R210, R511 | Gate Driver, Sense |
| 2 | `CL21B475KAFNNNE` | `C98195` | 4.7u | C_0805_2012Metric | C207, C403 | Gate Driver, MCU |
| 1 | `-` | `-` | PHASE_A | SolderWire-2.5sqmm_1x01_D2.4mm_OD3.6mm_Relief | J301 | Power Stage |
| 1 | `-` | `-` | PHASE_B | SolderWire-2.5sqmm_1x01_D2.4mm_OD3.6mm_Relief | J302 | Power Stage |
| 1 | `-` | `-` | PHASE_C | SolderWire-2.5sqmm_1x01_D2.4mm_OD3.6mm_Relief | J303 | Power Stage |
| 1 | `-` | `-` | SWD | PinHeader_2x05_P1.27mm_Vertical | J401 | MCU |
| 1 | `-` | `-` | SIGNAL | PinHeader_1x04_P2.54mm_Vertical | J402 | MCU |
| 1 | `-` | `-` | VBAT+ | SolderWire-2.5sqmm_1x01_D2.4mm_OD3.6mm_Relief | J101 | Power Input |
| 1 | `-` | `-` | VBAT- | SolderWire-2.5sqmm_1x01_D2.4mm_OD3.6mm_Relief | J102 | Power Input |
| 1 | `CC0603KRX7R9BB104` | `C14663` | 100n/16V | C_0603_1608Metric | C205 | Gate Driver |
| 1 | `CC0603KRX7R9BB104` | `C14663` | 100n VREF+ | C_0603_1608Metric | C404 | MCU |
| 1 | `CC0603KRX7R9BB104` | `C14663` | 100n NRST | C_0603_1608Metric | C406 | MCU |
| 1 | `CC0603KRX7R9BB104` | `C14663` | 100n VREF | C_0603_1608Metric | C503 | Sense |
| 1 | `CL10B105KA8NNNC` | `C29936` | 1u/25V | C_0603_1608Metric | C202 | Gate Driver |
| 1 | `CL10B105KA8NNNC` | `C29936` | 1u | C_0603_1608Metric | C208 | Gate Driver |
| 1 | `CL10B105KA8NNNC` | `C29936` | 1u VREF+ | C_0603_1608Metric | C405 | MCU |
| 1 | `CL10B473KB8NNNC` | `C1622` | 47n/50V | C_0603_1608Metric | C201 | Gate Driver |
| 1 | `DRV8323RSRGZT` | `C2653553` | DRV8323RS | Texas_RGZ0048A_VQFN-48-1EP_7x7mm_P0.5mm_EP5.15x5.15mm_ThermalVias | U201 | Gate Driver |
| 1 | `FRC0603F1002TS` | `C2906982` | IDRIVE | R_0603_1608Metric | R203 | Gate Driver |
| 1 | `FRC0603F1002TS` | `C2906982` | VDS | R_0603_1608Metric | R204 | Gate Driver |
| 1 | `FRC0603F1002TS` | `C2906982` | MODE | R_0603_1608Metric | R205 | Gate Driver |
| 1 | `FRC0603F1002TS` | `C2906982` | GAIN | R_0603_1608Metric | R206 | Gate Driver |
| 1 | `FRC0603F1002TS` | `C2906982` | 10k SDO | R_0603_1608Metric | R207 | Gate Driver |
| 1 | `FRC0603F1002TS` | `C2906982` | 10k nFAULT | R_0603_1608Metric | R208 | Gate Driver |
| 1 | `FRC0603F1002TS` | `C2906982` | 10k EN pd | R_0603_1608Metric | R209 | Gate Driver |
| 1 | `FRC0603F3322TS` | `C2933200` | 33.2k | R_0603_1608Metric | R201 | Gate Driver |
| 1 | `NCP18XH103F03RB` | `C13564` | 10k NTC | R_0603_1608Metric | R513 | Sense |
| 1 | `SLS6D38S330MTT` | `C364136` | 33u | L_7.3x7.3_H3.5 | L201 | Gate Driver |
| 1 | `SMBJ20A` | `C364296` | SMBJ20A | D_SMB | D101 | Power Input |
| 1 | `STM32G071CBT6` | `C432212` | STM32G071CBT6 | LQFP-48_7x7mm_P0.5mm | U401 | MCU |
| 1 | `XL-1608UGC-04` | `C965804` | green | LED_0603_1608Metric | D401 | MCU |

---

## Lines needing attention

| MPN | Note |
|---|---|
| `GRM32DR71E106KA12L` | 24 off. Derates to ~5-6 uF at 12 V bias - ESC-001 |
| `TPHR8504PL,L1Q(M` | 12 off, 2 per switch position. 40 V on a 12.6 V bus is deliberate - see docs/architecture.md |
| `SN74LVC1G97DBVR` | Shoot-through interlock. Wired per SCES416N Fig 6 |
| `HoJLR2512-3W-1mR-1%` | 4 in parallel = 0.25 mOhm. Needs a Kelvin sense tap in layout - ESC-005 |
| `SPZ1EM331F11O00R` | Through-hole radial. ~2.8 A ripple each - ESC-001 |
| `DRV8323RSRGZT` | SPI variant. RH (C543035) is pin-compatible - see docs/gate-driver-config.md before substituting |
| `STM32G071CBT6` | 48-pin part is REQUIRED: it is the only one that frees PB12/TIM1_BKIN. Symbol is KiCad's G081CBTx renamed |

## Before ordering

1. Wire the schematic -- quantities here are pre-wiring estimates.
2. Refresh stock for every line; flag anything under 10x requirement.
3. Record a second-source C-number for each thin line in that part's `manufacturing/parts/{Vendor}/{MPN}/{MPN}.md`.
4. Resolve everything in `manufacturing/stm32mp157-devkit/ISSUES.md` or defer it explicitly.
5. Re-run `python3 scripts/verify_project.py`.
6. Re-check stock immediately before placing the order -- do not order against numbers from a previous session.

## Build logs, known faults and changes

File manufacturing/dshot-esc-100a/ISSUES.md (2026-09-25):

# Board Issues — dshot-esc-100a

Open items. Each one is something that is **assumed rather than verified**,
or a decision deliberately deferred. Nothing here is a known-bad design;
they are the places where a second pass is required before fabrication.

Status: `OPEN` | `RESOLVED` | `WONTFIX`

---

## ESC-001 — Input ripple current budget is not closed  ·  OPEN  ·  high

A three-phase inverter's input ripple peaks near `0.5 × I_dc` RMS, so
**~50 A RMS at 100 A**. The on-board bank covers:

- 3 × 330 µF polymer @ ~2.8 A ripple each = **8.4 A**
- 24 × 10 µF X7R 1210 @ ~1.5-2 A each = **36-48 A**

Two things are unverified. First, the MLCC ripple figure is a rule of
thumb, not a vendor number. Second, a 10 µF 25 V X7R 1210 typically
derates to 5-6 µF at 12 V DC bias, so the array's *effective* capacitance
is roughly half its nameplate.

**Action:** pull vendor DC-bias and ripple curves for the exact MPNs
(C77100 / C160677) and recompute. Regardless of outcome, the mitigation
every ESC in this class uses is a **low-ESR capacitor at the battery
connector on short leads** — lead inductance dominates, not the on-board
bank. Document it as a required accessory.

## ESC-002 — SPI alternate-function numbers unverified  ·  OPEN  ·  low

PB10/PB11/PB2 are the correct *pins* for SPI2 on STM32G0, but the AF index
for each has not been read out of DS12232 Table 13.

**Mitigated by design:** `firmware/drv8323.c` bit-bangs SPI as plain GPIO,
so nothing depends on the AF table. Hardware SPI2 is an optimisation to
enable only after the table is checked.

## ESC-003 — TIM1_BKIN on PB12 unverified  ·  OPEN  ·  medium

The hardware fault-break path (`nFAULT` → `TIM1_BKIN` → all six outputs
forced inactive with no firmware involved) assumes PB12 carries TIM1_BKIN
on this package. Not yet confirmed against DS12232.

**Fallback if wrong:** EXTI on the same pin. Costs ~1 µs of interrupt
latency instead of being instantaneous. The board is still protected by
dead-time layers 1-4; only layer 0 degrades.

## ESC-004 — High-current terminals  ·  RESOLVED  ·  2026-09-25

The placeholder `SolderWire-2.5sqmm` footprint was good for ~25 A and its
strain-relief tail was 25 mm long, which made it unplaceable.

Replaced with `dshot-esc-100a:HighCurrentTerminal_8AWG`
(`scripts/gen_footprints.py`): a 3.6 mm plated hole for 8 AWG conductor
(3.26 mm) with a 9 mm annular pad on **both** outer layers, solder mask
pulled back so the joint can be flooded. ~50 mm² of copper per terminal
spreading into the pour.

Applied to `J101`, `J102`, `J301-J303` in the schematic, the parts
catalogue and the PCB.

## ESC-013 — 2 oz copper vs the driver's thermal-via footprint  ·  RESOLVED  ·  2026-09-25

KiCad's `..._ThermalVias` variant of the DRV8323R land pattern embeds
0.2 mm vias. This board is 2 oz outer copper, where 0.3 mm is the
realistic fab minimum, and DRC flagged 25 `drill_out_of_range` errors.

Switched to the plain `Texas_RGZ0048A_VQFN-48-1EP_7x7mm_P0.5mm_EP5.15x5.15mm`
land pattern. A 0.3 mm thermal via array gets placed by hand during
routing — see `docs/layout.md` rule 6.

## ESC-005 — Shunt Kelvin connection not yet expressed  ·  OPEN  ·  medium

`SPA`/`SNA` connect to the shunt node by name. At 0.25 mΩ, a few
milliohms of trace resistance in the sense path is a large fractional
error, so the sense pins must tap the shunt pads directly as a Kelvin
connection rather than joining the power pour.

Schematic-level nets are correct; this is a **layout constraint** to
encode in the design rules. Blocks the PCB pass, not the schematic.

## ESC-006 — No reverse-polarity protection  ·  OPEN  ·  by design

Deliberately omitted. An ideal-diode FET stage at 100 A adds ~0.5 mΩ
(~5 W) plus its own gate drive and a second failure mode. Mitigation is
the polarised XT90 connector.

**Revisit if** this board is ever used somewhere the connector cannot be
relied on.

## ESC-007 — Buck feedback divider unverified  ·  OPEN  ·  medium

`R201`/`R202` = 33.2 k / 10 k assumes a 0.765 V feedback reference,
giving `0.765 × (1 + 3.32) = 3.30 V`. The DRV8323R's integrated buck is an
LMR16006X, but the reference voltage has not been read out of SNVSA13. The
33 µH inductor and 10 µF output cap are likewise from the general LMR16006
application, not a worked calculation for this operating point.

**Consequence if wrong:** the 3V3 rail is off-target and the MCU may sit
outside 1.71-3.6 V. Check before first power-on.

## ESC-008 — VREF+ has no ferrite  ·  OPEN  ·  low

`U401` pin 5 (`VREF+`) ties straight to 3V3 with 1 µF ‖ 100 nF. Good
practice on a board switching 100 A is a ferrite bead between 3V3 and
VREF+. The ADC reads bus voltage, current and temperature — all slow — so
the impact is small, but it is nearly free to add.

## ESC-009 — DRV8323 propagation delay assumed  ·  OPEN  ·  low

The dead-time budget uses `t_PD ≈ 100 ns` for INx → GHx/GLx. Not yet read
from SLVSDJ3D §7.5. It **cancels to first order** between the turn-on and
turn-off paths, so the budget is insensitive to it; this is tidiness.

## ESC-010 — RH resistor values not transcribed  ·  OPEN  ·  medium

`R203-R206` are placeholder 10 k. The real values come from the 4- and
7-level input tables in SLVSDJ3D §8.5, which have not been transcribed.
**An RH build populated as-drawn will not have the intended IDRIVE, VDS,
MODE or GAIN settings.**

Blocks an RH build only. An RS build ignores these (they are DNP) and is
fully specified in `docs/gate-driver-config.md`.

## ESC-011 — `TARGET_VOLTAGE_DIVIDER` scaling unverified  ·  OPEN  ·  low

Set to 110 for the 100 k / 10 k (11:1) divider, on the assumption that
AM32's constant is `ratio × 10`. Shipping targets use 110 and 210, which
is consistent, but the formula has not been read out of AM32's ADC code.

**Consequence if wrong:** reported battery voltage is scaled wrong, and
low-voltage cutoff triggers at the wrong point. Cosmetic on the bench,
potentially damaging to a LiPo in flight.

## ESC-012 — Thermal design is stated, not simulated  ·  OPEN  ·  medium

`docs/power-budget.md` puts ~19 W at 100 A continuous into the board. The
outline is now fixed at **80 × 68 mm**, which is 0.35 W/cm² rather than
the 1.1 W/cm² the original 50 × 35 mm estimate assumed — better, but
still **not passively coolable**; the design assumes propwash or forced
air.

No thermal simulation has been run and no copper area has been sized. The
150 A figure is a 10-second burst bounded by thermal mass, not a steady
state. Blocks the PCB pass.

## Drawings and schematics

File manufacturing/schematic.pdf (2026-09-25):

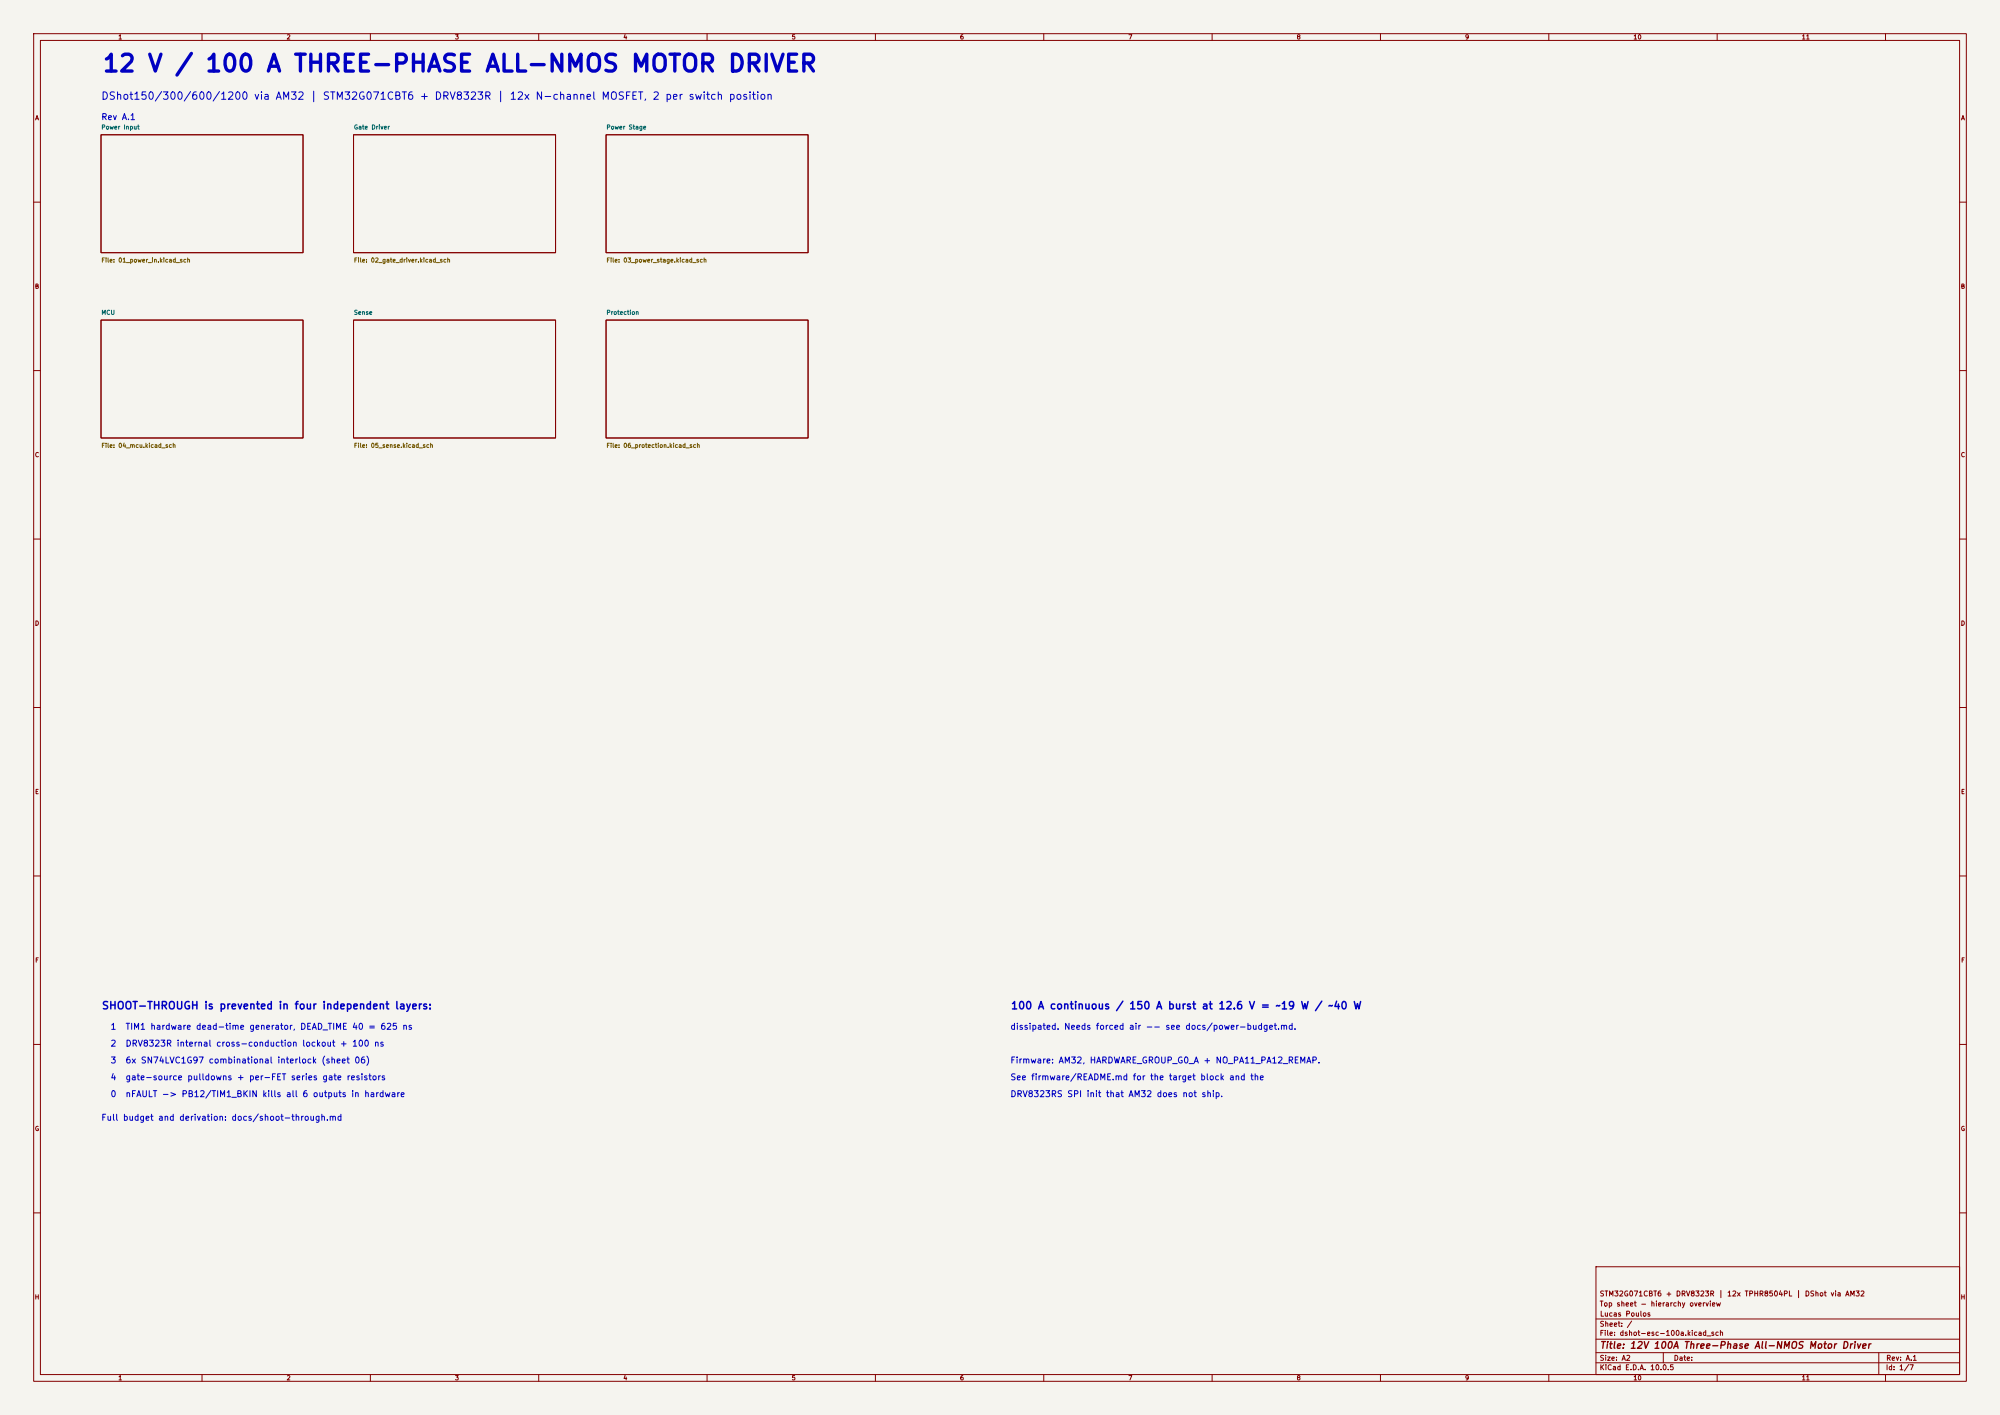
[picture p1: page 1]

12 V / 100 A THREE-PHASE ALL-NMOS MOTOR DRIVER
Power Input File: 01_power_in.kicad_sch MCU

DShot150/300/600/1200 via AM32 | STM32G071CBT6 + DRV8323R | 12x N-channel MOSFET, 2 per switch position

SHOOT-THROUGH is prevented in four independent layers:

dissipated. Needs forced air -- see docs/power-budget.md.

2 DRV8323R internal cross-conduction lockout + 100 ns 3 6x SN74LVC1G97 combinational interlock (sheet 06)

Firmware: AM32, HARDWARE_GROUP_G0_A + NO_PA11_PA12_REMAP.
See firmware/README.md for the target block and the

4 gate-source pulldowns + per-FET series gate resistors
0 nFAULT -> PB12/TIM1_BKIN kills all 6 outputs in hardware

DRV8323RS SPI init that AM32 does not ship.

Full budget and derivation: docs/shoot-through.md

STM32G071CBT6 + DRV8323R | 12x TPHR8504PL | DShot via AM32
Top sheet - hierarchy overview
Lucas Poulos
Sheet: /
File: dshot-esc-100a.kicad_sch
Title: 12V 100A Three-Phase All-NMOS Motor Driver

Size: A2 | Rev: A.1
KiCad E.D.A. 10.0.5 | Id: 1/7

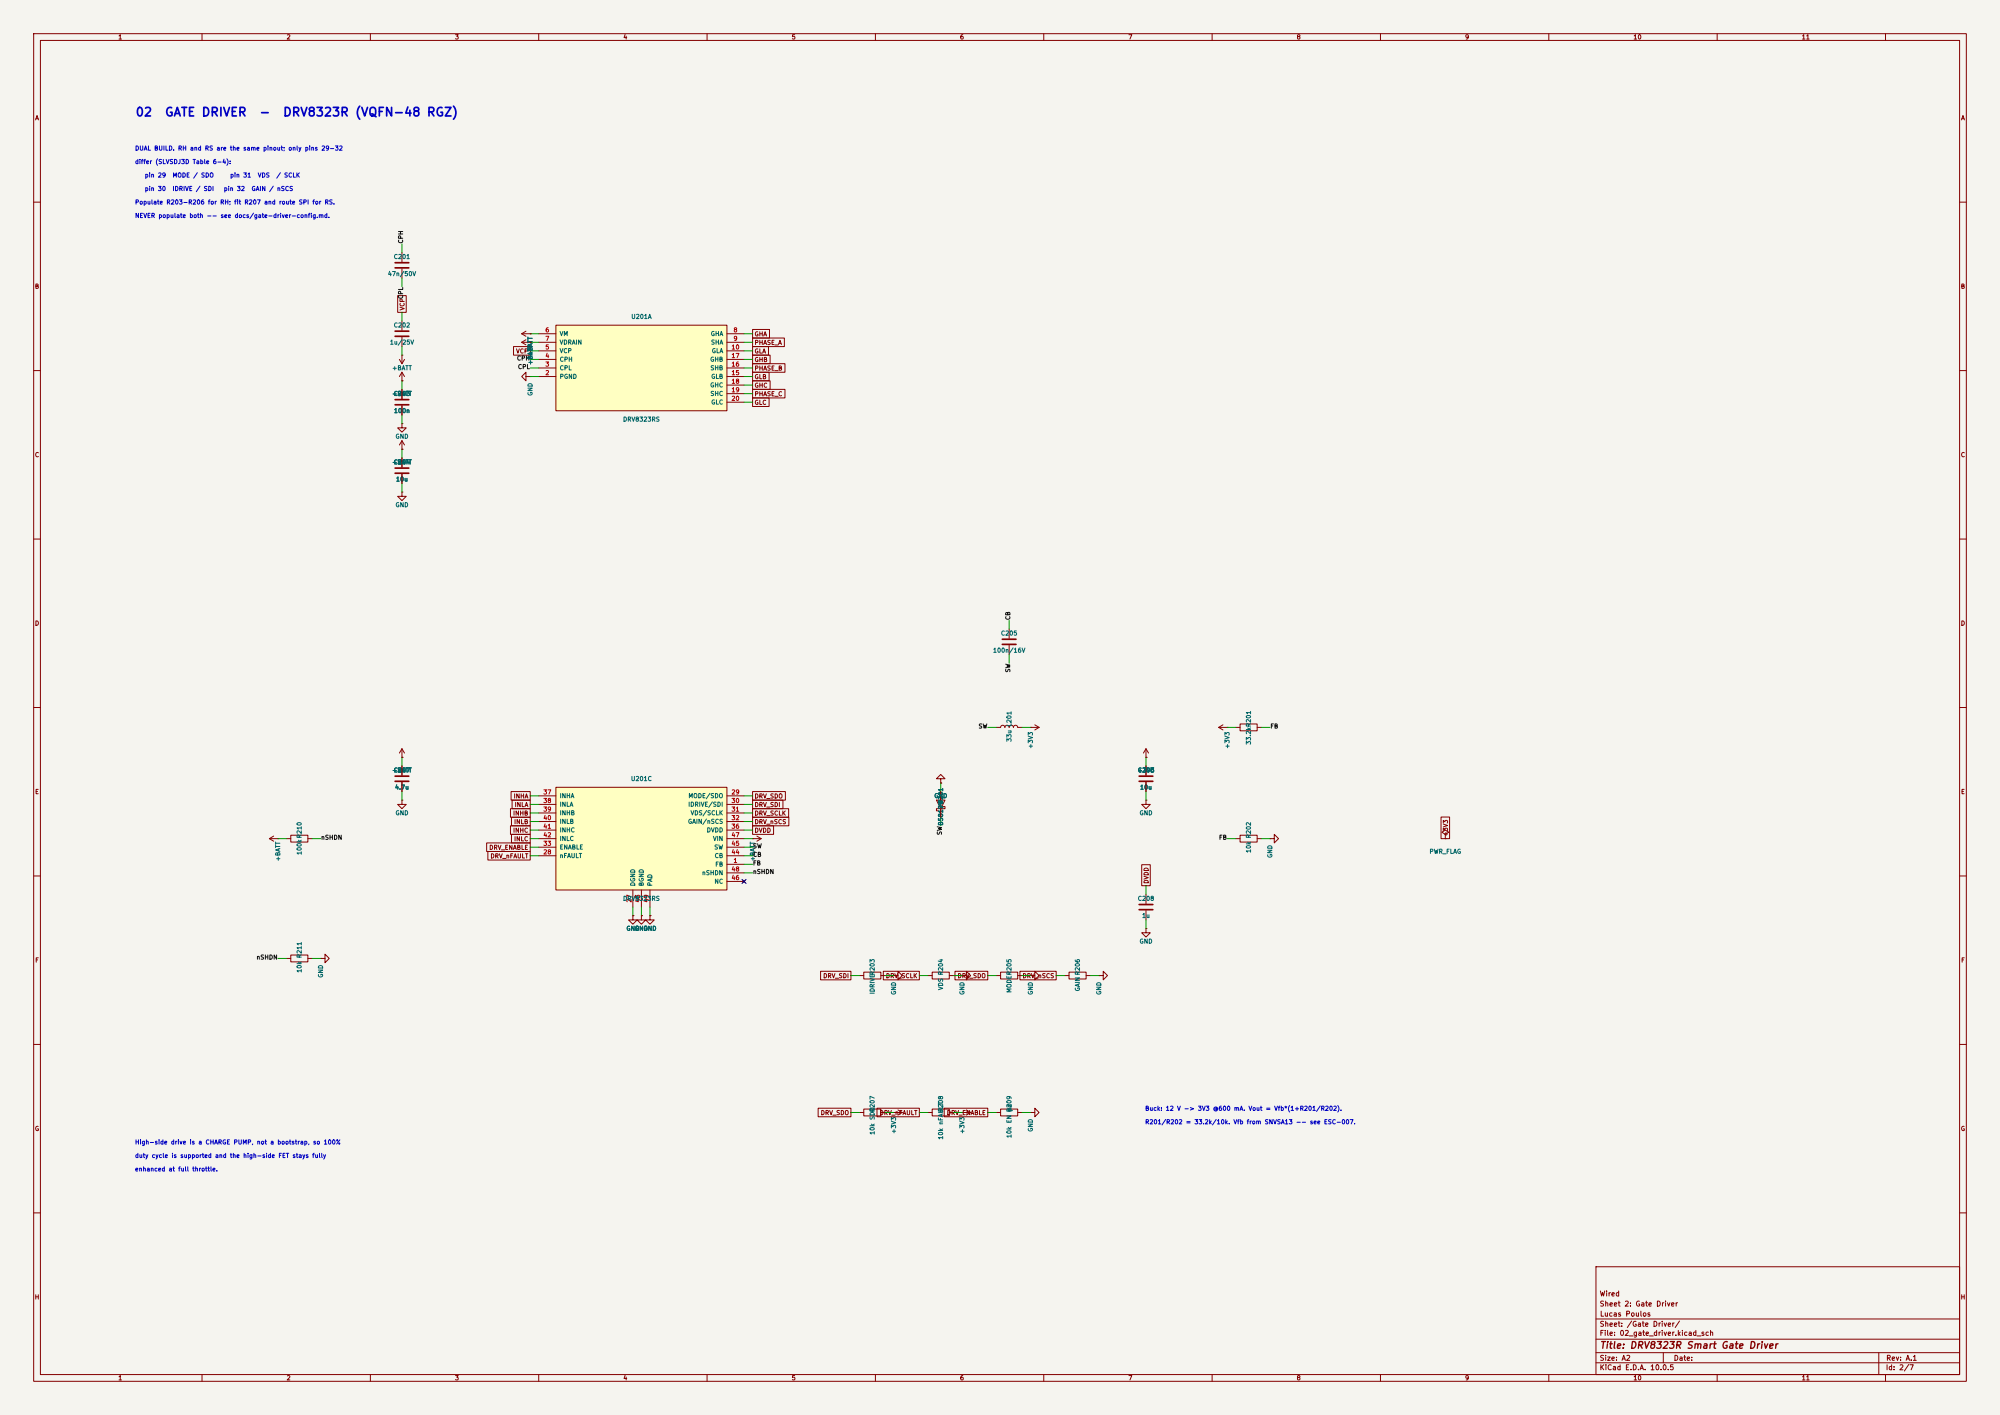
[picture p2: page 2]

differ (SLVSDJ3D Table 6-4): DUAL BUILD. RH and RS are the same pinout; only pins 29-32 02 GATE DRIVER - DRV8323R (VQFN-48 RGZ)

Buck: 12 V -> 3V3 @600 mA. Vout = Vfb*(1+R201/R202).

R201/R202 = 33.2k/10k. Vfb from SNVSA13 -- see ESC-007.

enhanced at full throttle. High-side drive is a CHARGE PUMP, not a bootstrap, so 100%

duty cycle is supported and the high-side FET stays fully

Sheet: /Gate Driver/
File: 02_gate_driver.kicad_sch
Title: DRV8323R Smart Gate Driver

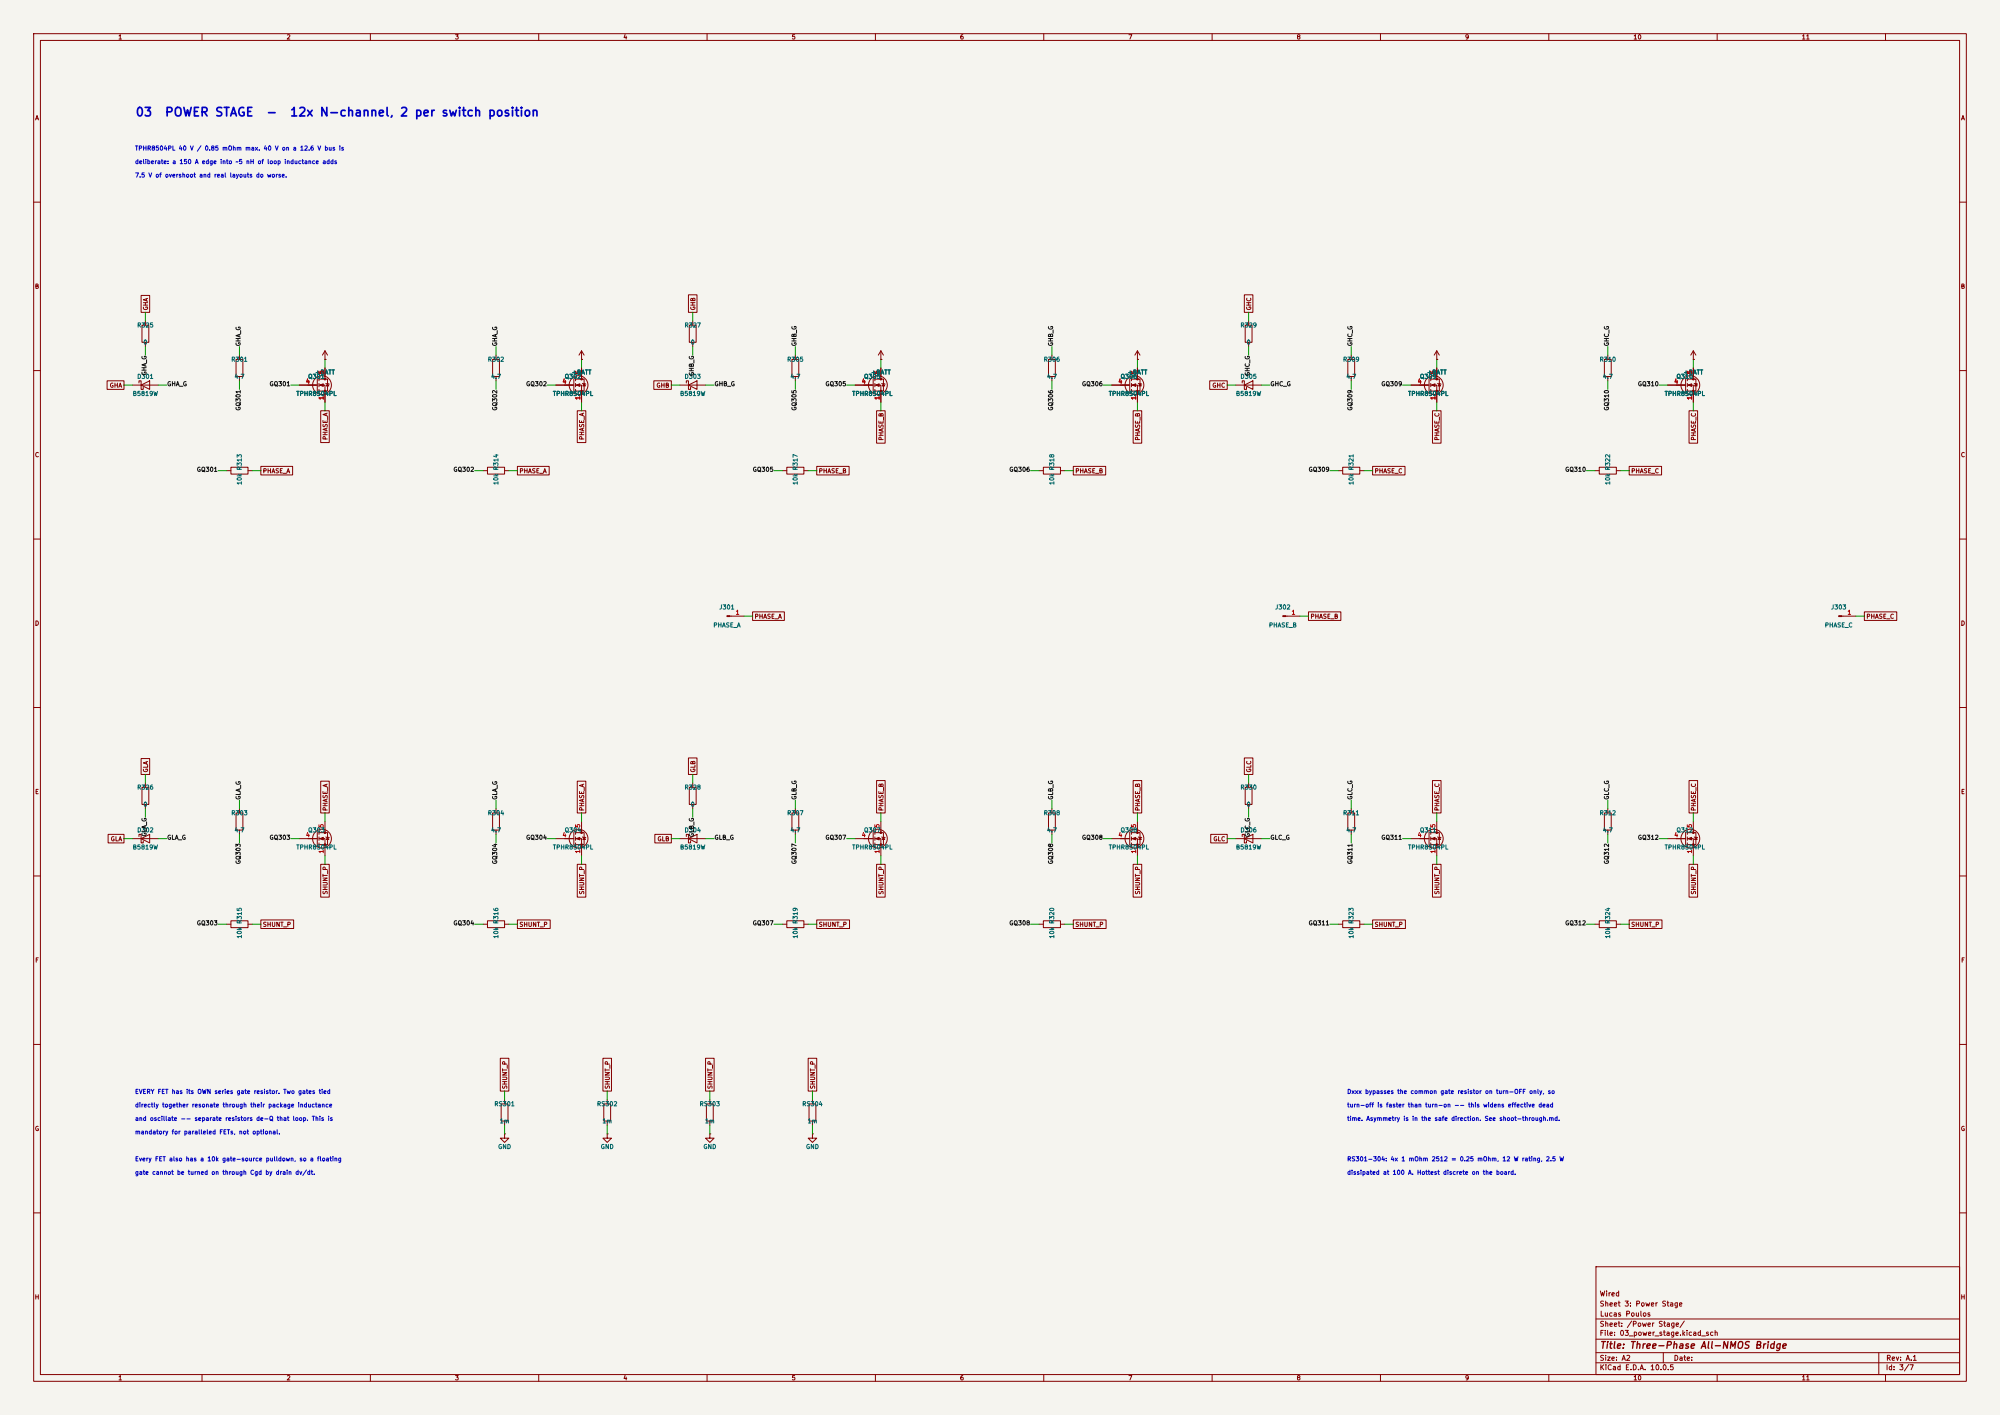
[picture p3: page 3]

03 POWER STAGE - 12x N-channel, 2 per switch position

TPHR8504PL 40 V / 0.85 mOhm max. 40 V on a 12.6 V bus is

deliberate: a 150 A edge into ~5 nH of loop inductance adds

7.5 V of overshoot and real layouts do worse.

directly together resonate through their package inductance EVERY FET has its OWN series gate resistor. Two gates tied

Dxxx bypasses the common gate resistor on turn-OFF only, so

turn-off is faster than turn-on -- this widens effective dead

and oscillate -- separate resistors de-Q that loop. This is gate cannot be turned on through Cgd by drain dv/dt.

time. Asymmetry is in the safe direction. See shoot-through.md.

mandatory for paralleled FETs, not optional.

Every FET also has a 10k gate-source pulldown, so a floating

dissipated at 100 A. Hottest discrete on the board. RS301-304: 4x 1 mOhm 2512 = 0.25 mOhm, 12 W rating, 2.5 W

Sheet: /Power Stage/
File: 03_power_stage.kicad_sch
Title: Three-Phase All-NMOS Bridge

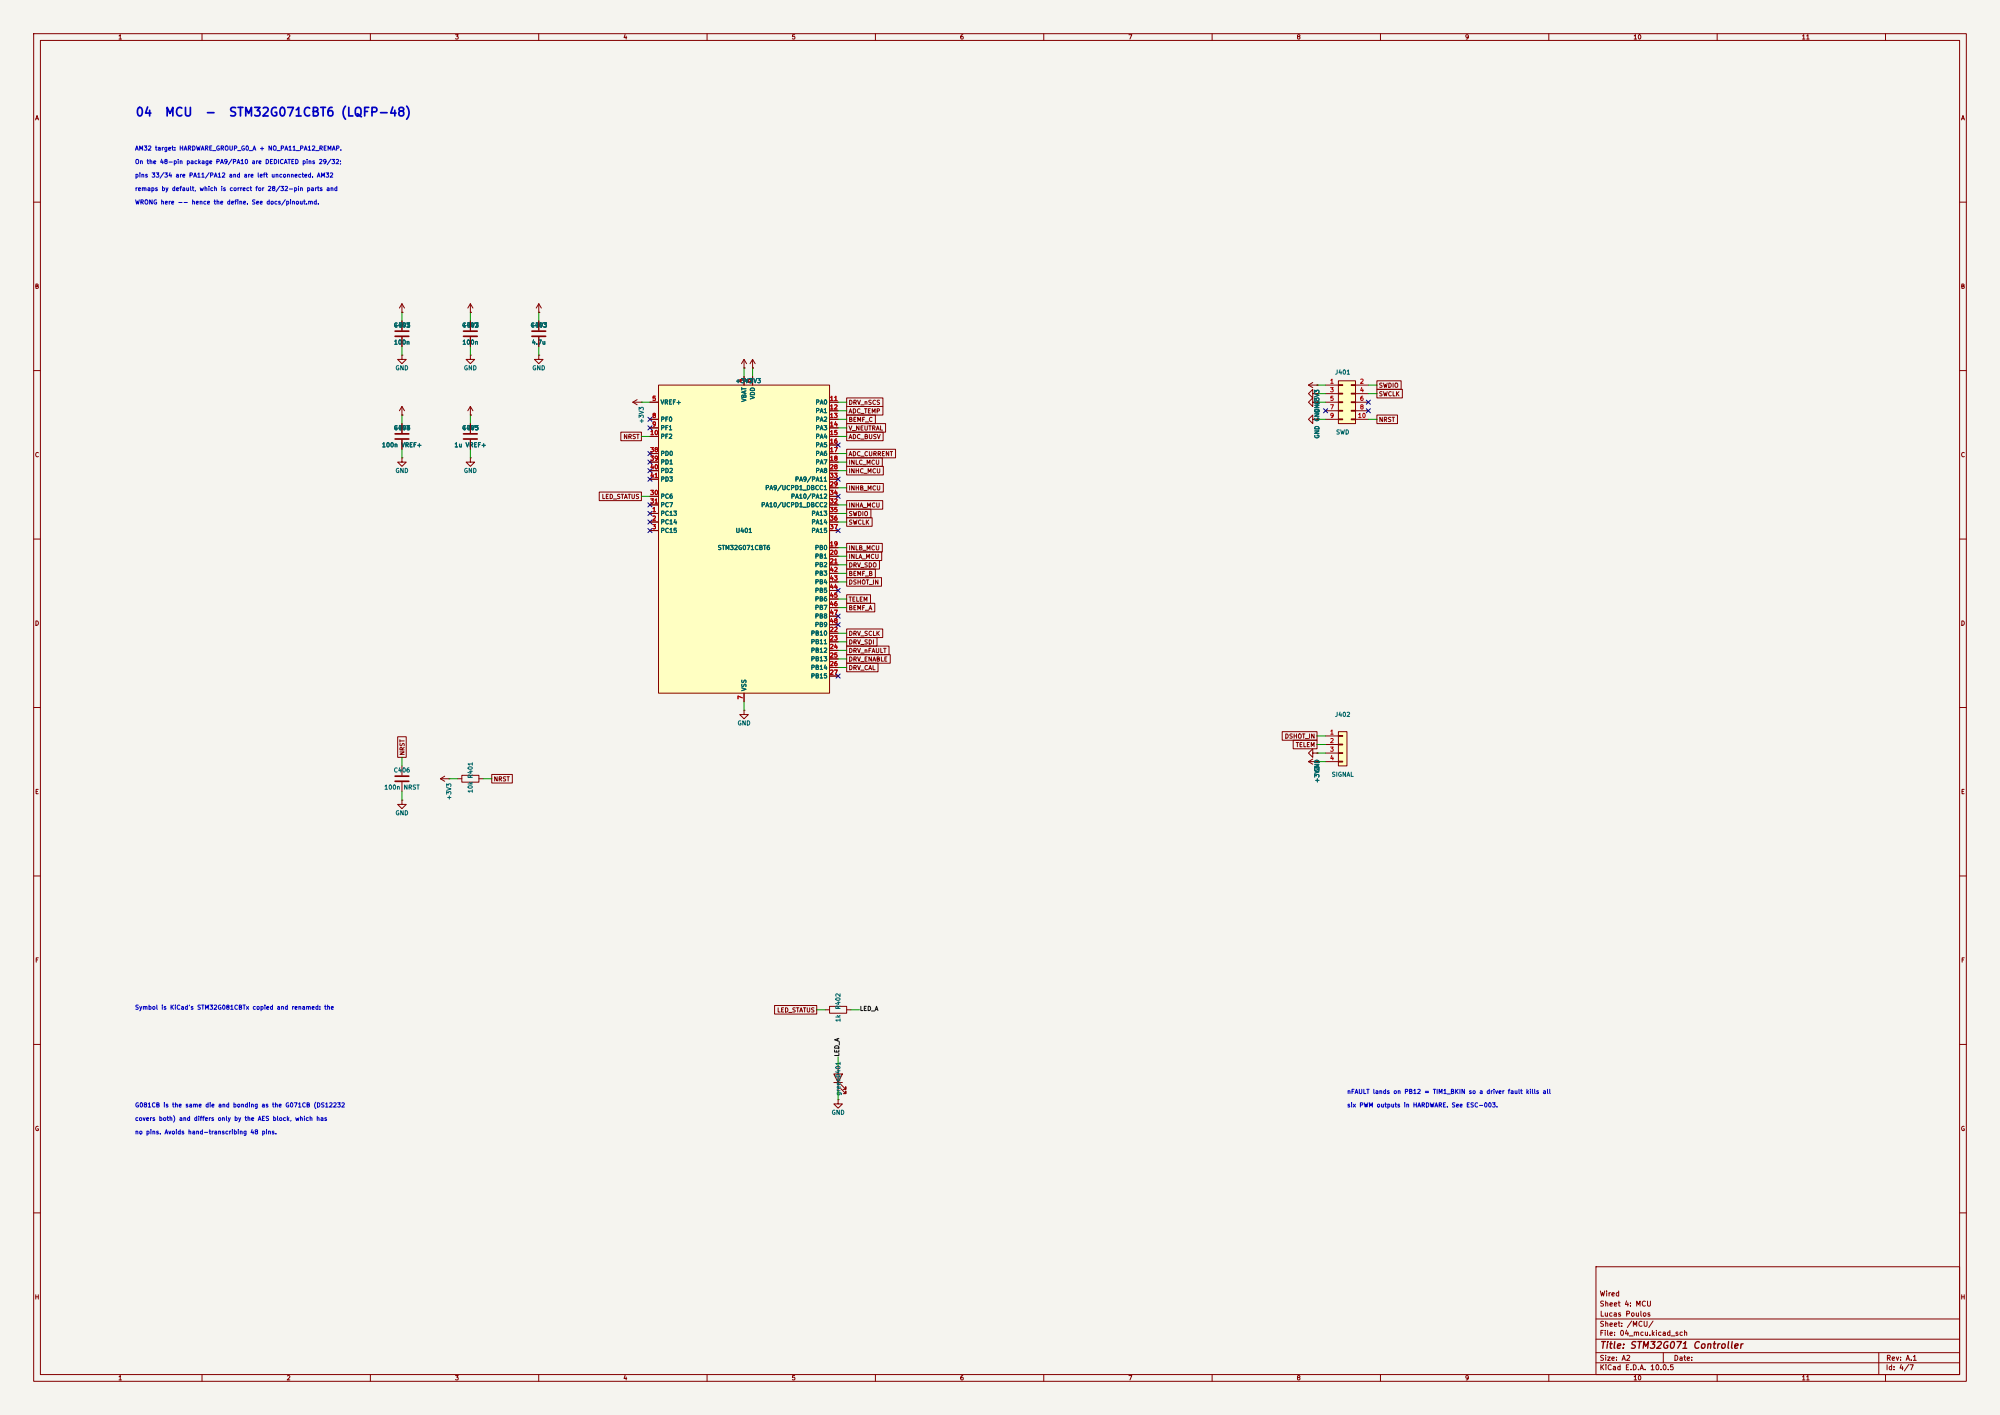
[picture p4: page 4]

pins 33/34 are PA11/PA12 and are left unconnected. AM32 On the 48-pin package PA9/PA10 are DEDICATED pins 29/32; AM32 target: HARDWARE_GROUP_G0_A + NO_PA11_PA12_REMAP. 04 MCU - STM32G071CBT6 (LQFP-48)

WRONG here -- hence the define. See docs/pinout.md. remaps by default, which is correct for 28/32-pin parts and

Symbol is KiCad's STM32G081CBTx copied and renamed: the G081CB is the same die and bonding as the G071CB (DS12232
LED_A no pins. Avoids hand-transcribing 48 pins.

six PWM outputs in HARDWARE. See ESC-003. nFAULT lands on PB12 = TIM1_BKIN so a driver fault kills all

covers both) and differs only by the AES block, which has

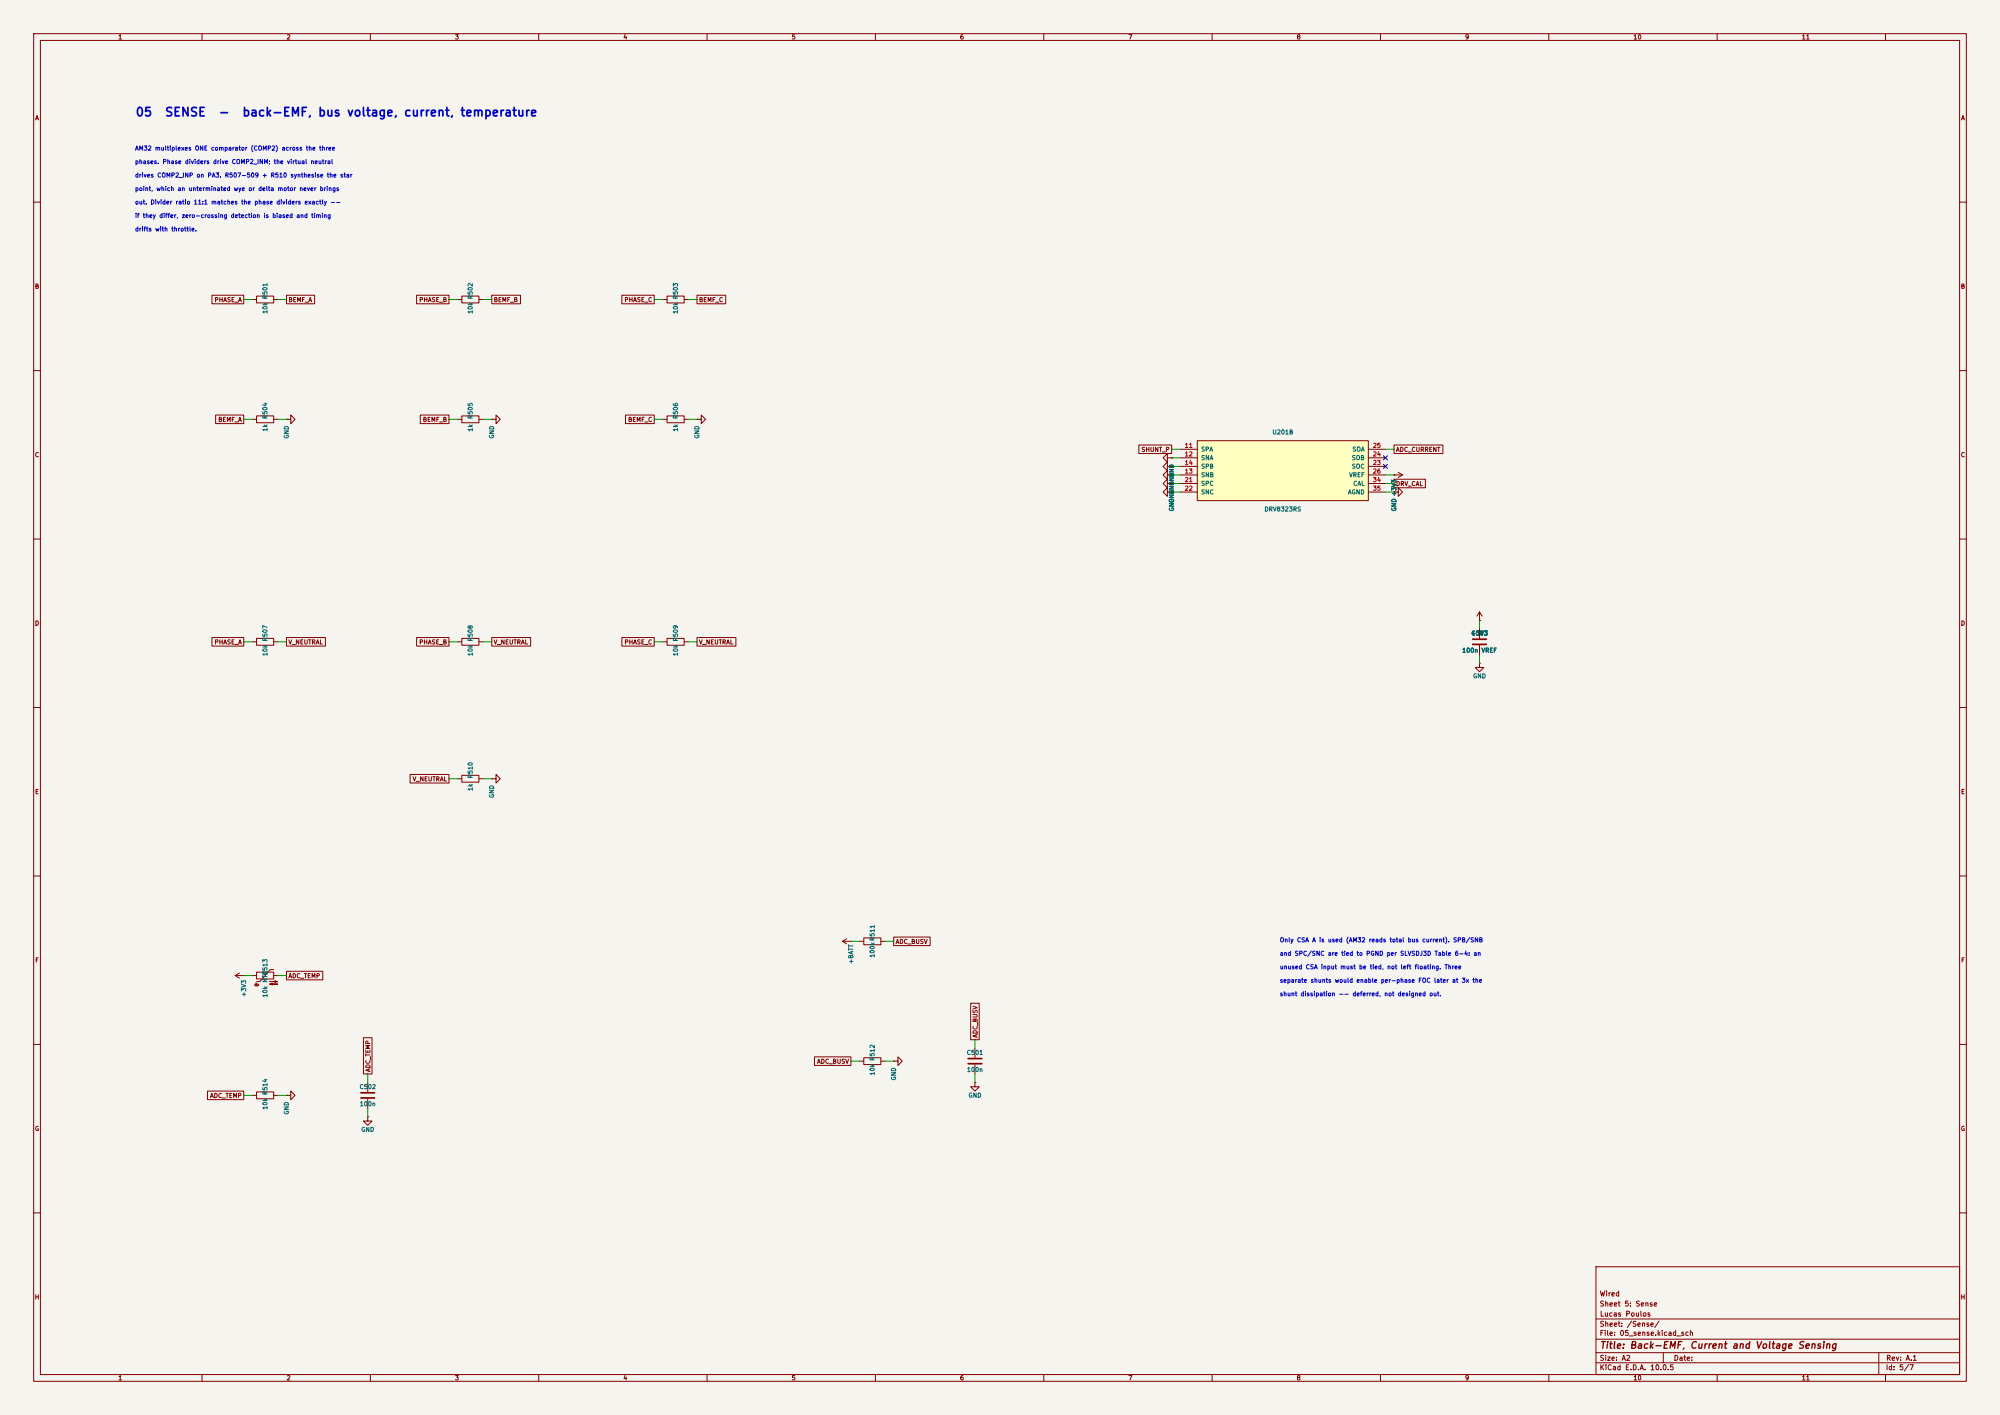
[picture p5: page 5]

point, which an unterminated wye or delta motor never brings AM32 multiplexes ONE comparator (COMP2) across the three phases. Phase dividers drive COMP2_INM; the virtual neutral drives COMP2_INP on PA3. R507-509 + R510 synthesise the star

out. Divider ratio 11:1 matches the phase dividers exactly --

if they differ, zero-crossing detection is biased and timing

Only CSA A is used (AM32 reads total bus current). SPB/SNB

and SPC/SNC are tied to PGND per SLVSDJ3D Table 6-4: an

unused CSA input must be tied, not left floating. Three

separate shunts would enable per-phase FOC later at 3x the

shunt dissipation -- deferred, not designed out.

Sheet: /Sense/
File: 05_sense.kicad_sch
Title: Back-EMF, Current and Voltage Sensing

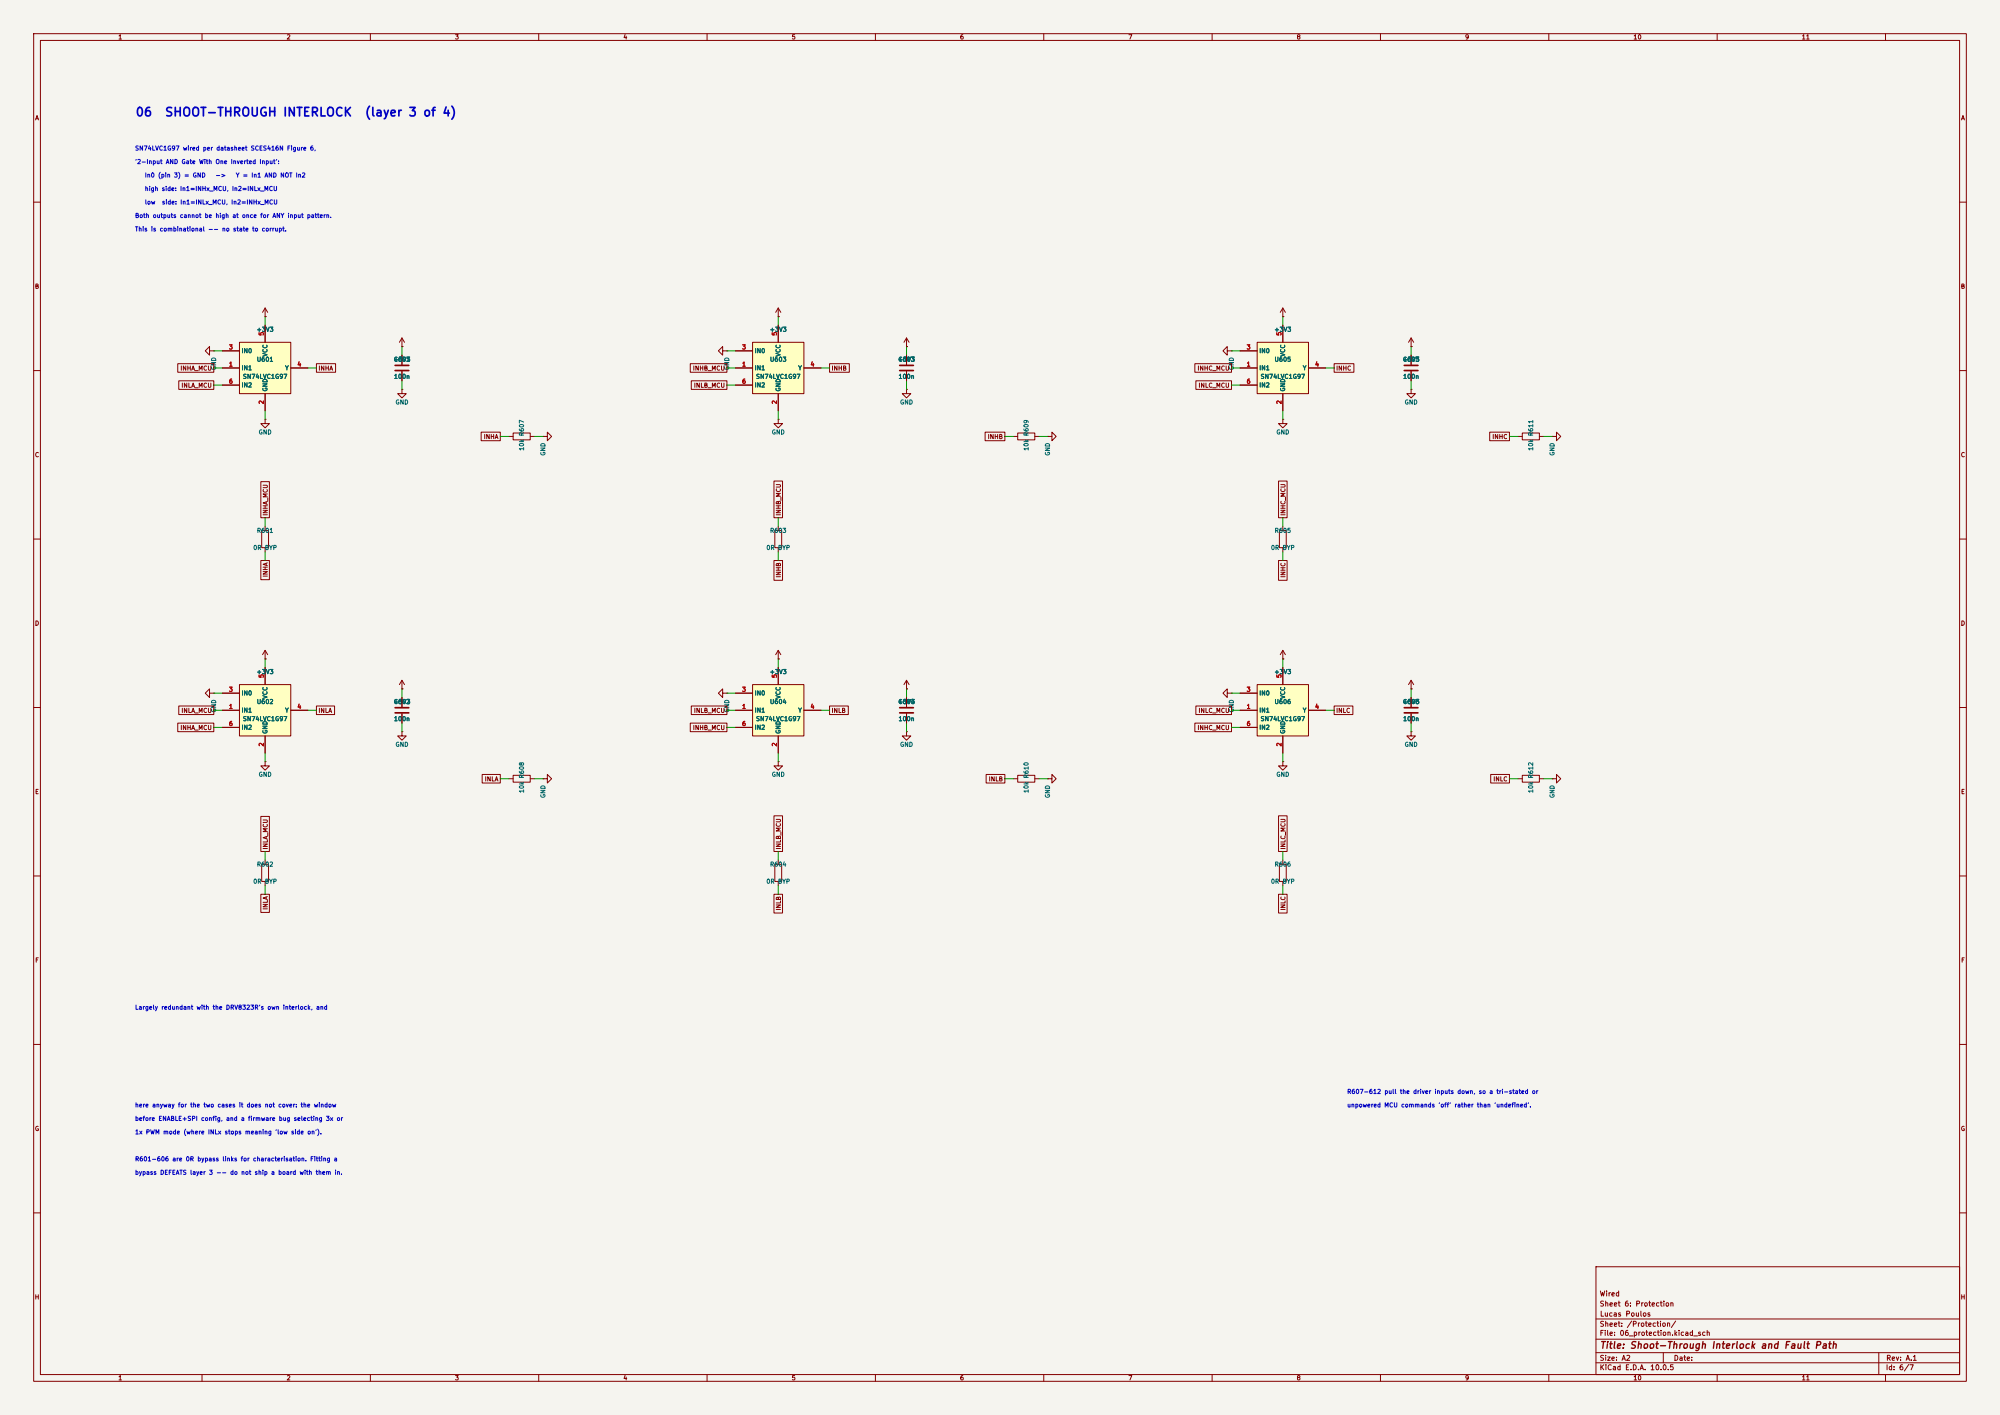
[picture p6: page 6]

06 SHOOT-THROUGH INTERLOCK (layer 3 of 4)

'2-Input AND Gate With One Inverted Input': SN74LVC1G97 wired per datasheet SCES416N Figure 6,

This is combinational -- no state to corrupt. Both outputs cannot be high at once for ANY input pattern. low side: In1=INLx_MCU, In2=INHx_MCU

Largely redundant with the DRV8323R's own interlock, and
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

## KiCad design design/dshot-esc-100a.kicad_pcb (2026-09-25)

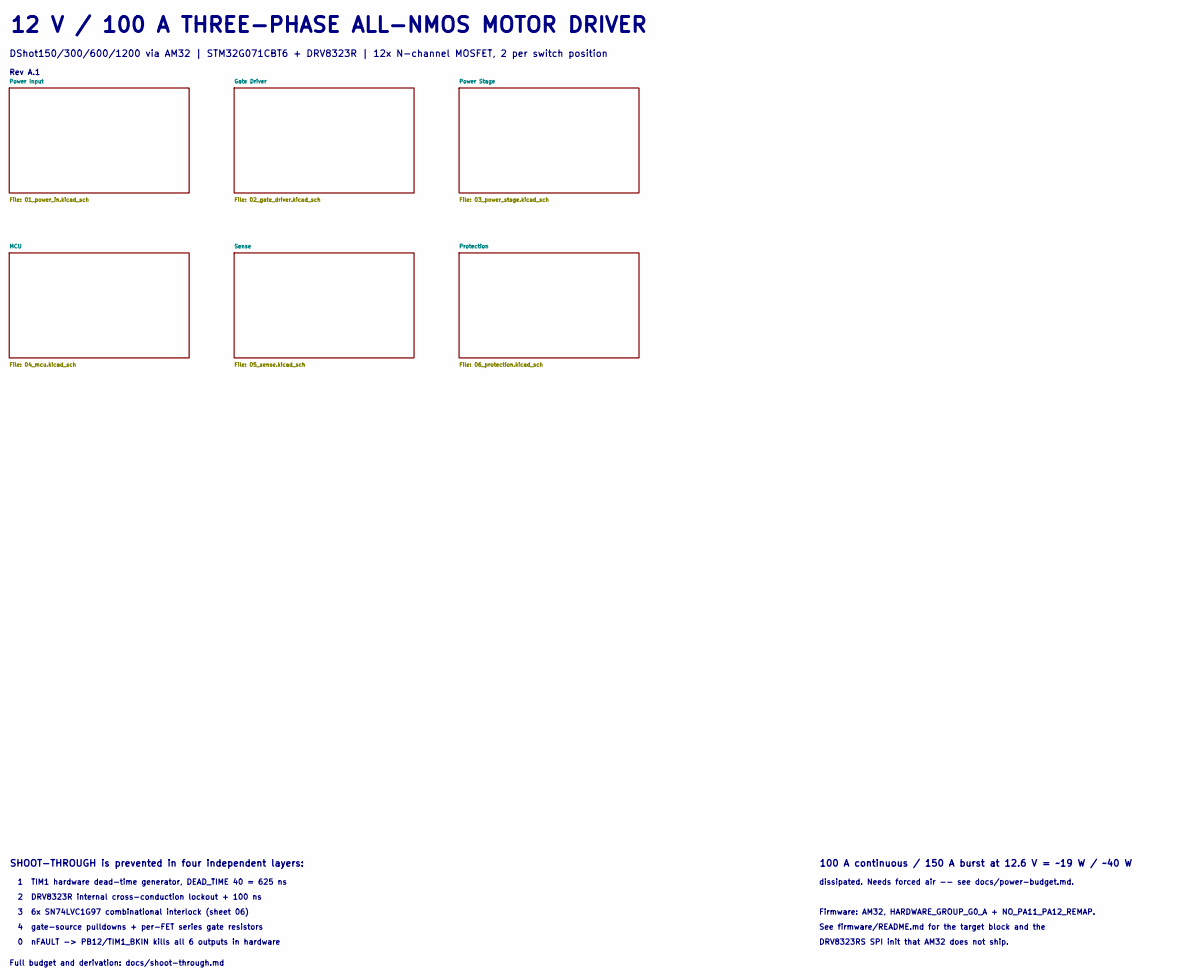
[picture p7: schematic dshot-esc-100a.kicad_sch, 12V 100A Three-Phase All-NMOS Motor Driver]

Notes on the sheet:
2 DRV8323R internal cross-conduction lockout + 100 ns
Full budget and derivation: docs/shoot-through.md
dissipated. Needs forced air -- see docs/power-budget.md.
12 V / 100 A THREE-PHASE ALL-NMOS MOTOR DRIVER
Rev A.1
See firmware/README.md for the target block and the
DRV8323RS SPI init that AM32 does not ship.
4 gate-source pulldowns + per-FET series gate resistors
SHOOT-THROUGH is prevented in four independent layers:
1 TIM1 hardware dead-time generator, DEAD_TIME 40 = 625 ns
Firmware: AM32, HARDWARE_GROUP_G0_A + NO_PA11_PA12_REMAP.
DShot150/300/600/1200 via AM32 | STM32G071CBT6 + DRV8323R | 12x N-channel MOSFET, 2 per switch position
0 nFAULT -> PB12/TIM1_BKIN kills all 6 outputs in hardware
3 6x SN74LVC1G97 combinational interlock (sheet 06)
100 A continuous / 150 A burst at 12.6 V = ~19 W / ~40 W

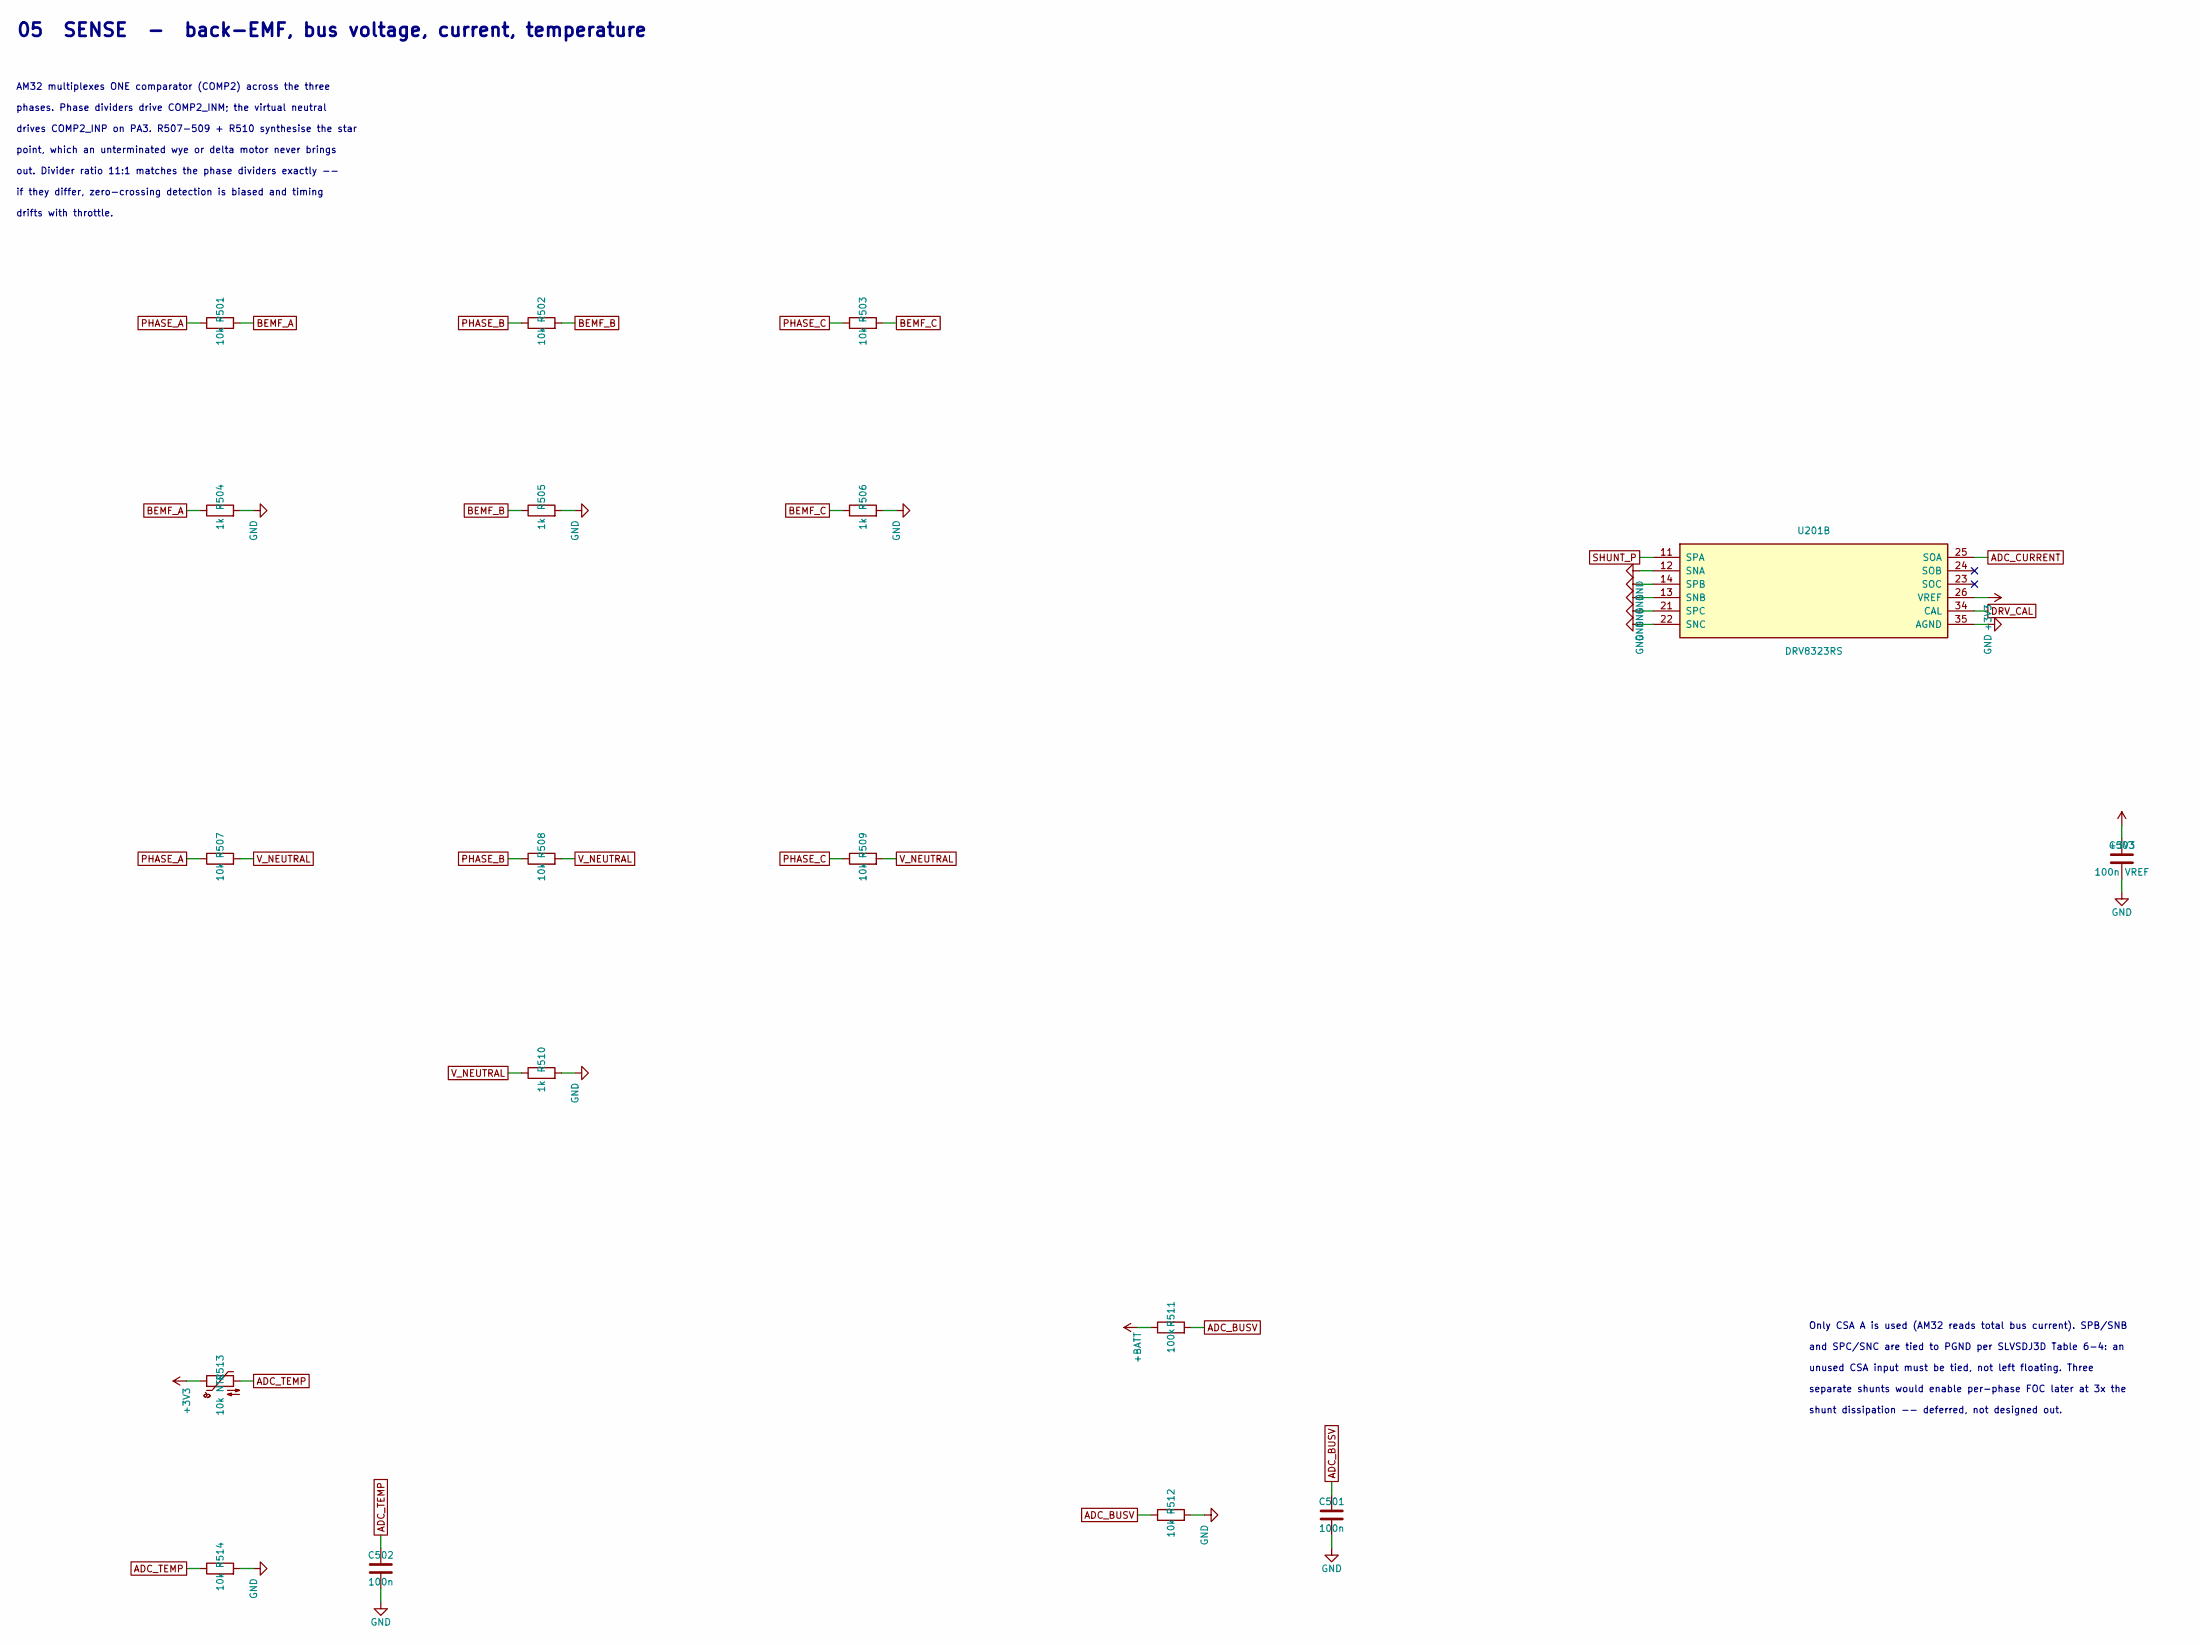
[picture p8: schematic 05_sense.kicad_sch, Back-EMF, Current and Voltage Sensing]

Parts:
C501, C502: 100n; C_0603_1608Metric; MPN CC0603KRX7R9BB104; LCSC C14663
C503: 100n VREF; C_0603_1608Metric; MPN CC0603KRX7R9BB104; LCSC C14663
R501, R502, R503, R507, R508, R509, R512, R514: 10k; R_0603_1608Metric; MPN FRC0603F1002TS; LCSC C2906982
R504, R505, R506, R510: 1k; R_0603_1608Metric; MPN FRC0603F1001TS; LCSC C2907002
R511: 100k; R_0603_1608Metric; MPN 0603WAF1003T5E; LCSC C25803
R513: 10k NTC; R_0603_1608Metric; MPN NCP18XH103F03RB; LCSC C13564
U201: DRV8323RS; Texas_RGZ0048A_VQFN-48-1EP_7x7mm_P0.5mm_EP5.15x5.15mm; MPN DRV8323RSRGZT; LCSC C2653553

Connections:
+3V3: C503.1, R513.1, U201.26 (VREF); also elsewhere on the board
+BATT: R511.1; also elsewhere on the board
ADC_BUSV: C501.1, R511.2, R512.1; also elsewhere on the board
ADC_CURRENT: U201.25 (SOA); also elsewhere on the board
ADC_TEMP: C502.1, R513.2, R514.1; also elsewhere on the board
BEMF_A: R501.2, R504.1; also elsewhere on the board
BEMF_B: R502.2, R505.1; also elsewhere on the board
BEMF_C: R503.2, R506.1; also elsewhere on the board
DRV_CAL: U201.34 (CAL); also elsewhere on the board
GND: C501.2, C502.2, C503.2, R504.2, R505.2, R506.2, R510.2, R512.2, R514.2, U201.12 (SNA), U201.13 (SNB), U201.14 (SPB), U201.21 (SPC), U201.22 (SNC), U201.35 (AGND); also elsewhere on the board
PHASE_A: R501.1, R507.1; also elsewhere on the board
PHASE_B: R502.1, R508.1; also elsewhere on the board
PHASE_C: R503.1, R509.1; also elsewhere on the board
SHUNT_P: U201.11 (SPA); also elsewhere on the board
V_NEUTRAL: R507.2, R508.2, R509.2, R510.1; also elsewhere on the board

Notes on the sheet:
point, which an unterminated wye or delta motor never brings
out. Divider ratio 11:1 matches the phase dividers exactly --
shunt dissipation -- deferred, not designed out.
05 SENSE - back-EMF, bus voltage, current, temperature
drives COMP2_INP on PA3. R507-509 + R510 synthesise the star
drifts with throttle.
unused CSA input must be tied, not left floating. Three
AM32 multiplexes ONE comparator (COMP2) across the three
phases. Phase dividers drive COMP2_INM; the virtual neutral
if they differ, zero-crossing detection is biased and timing
separate shunts would enable per-phase FOC later at 3x the
and SPC/SNC are tied to PGND per SLVSDJ3D Table 6-4: an
Only CSA A is used (AM32 reads total bus current). SPB/SNB

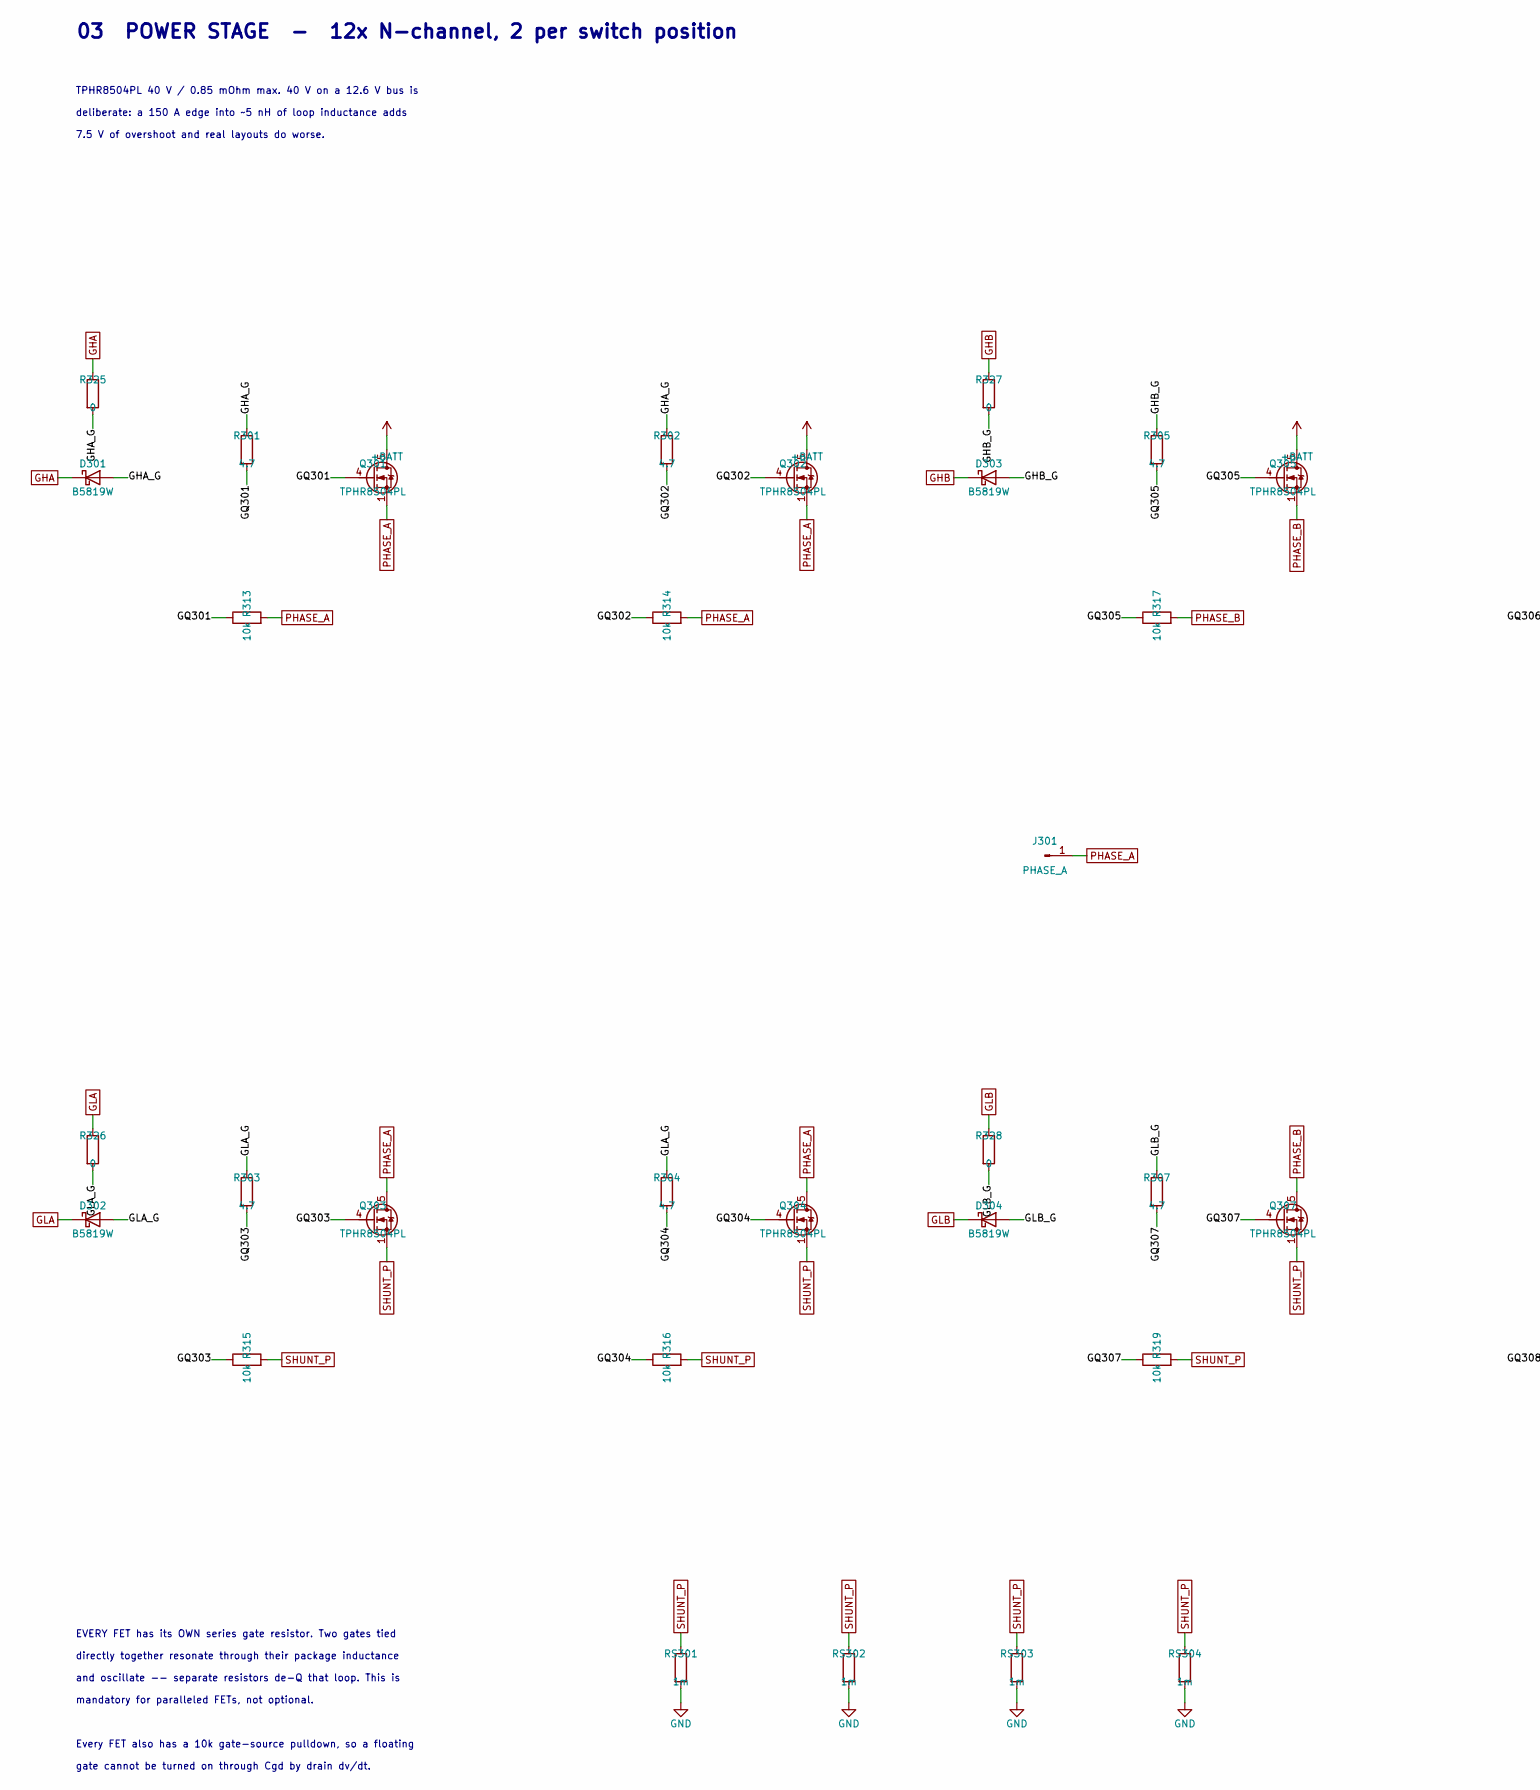
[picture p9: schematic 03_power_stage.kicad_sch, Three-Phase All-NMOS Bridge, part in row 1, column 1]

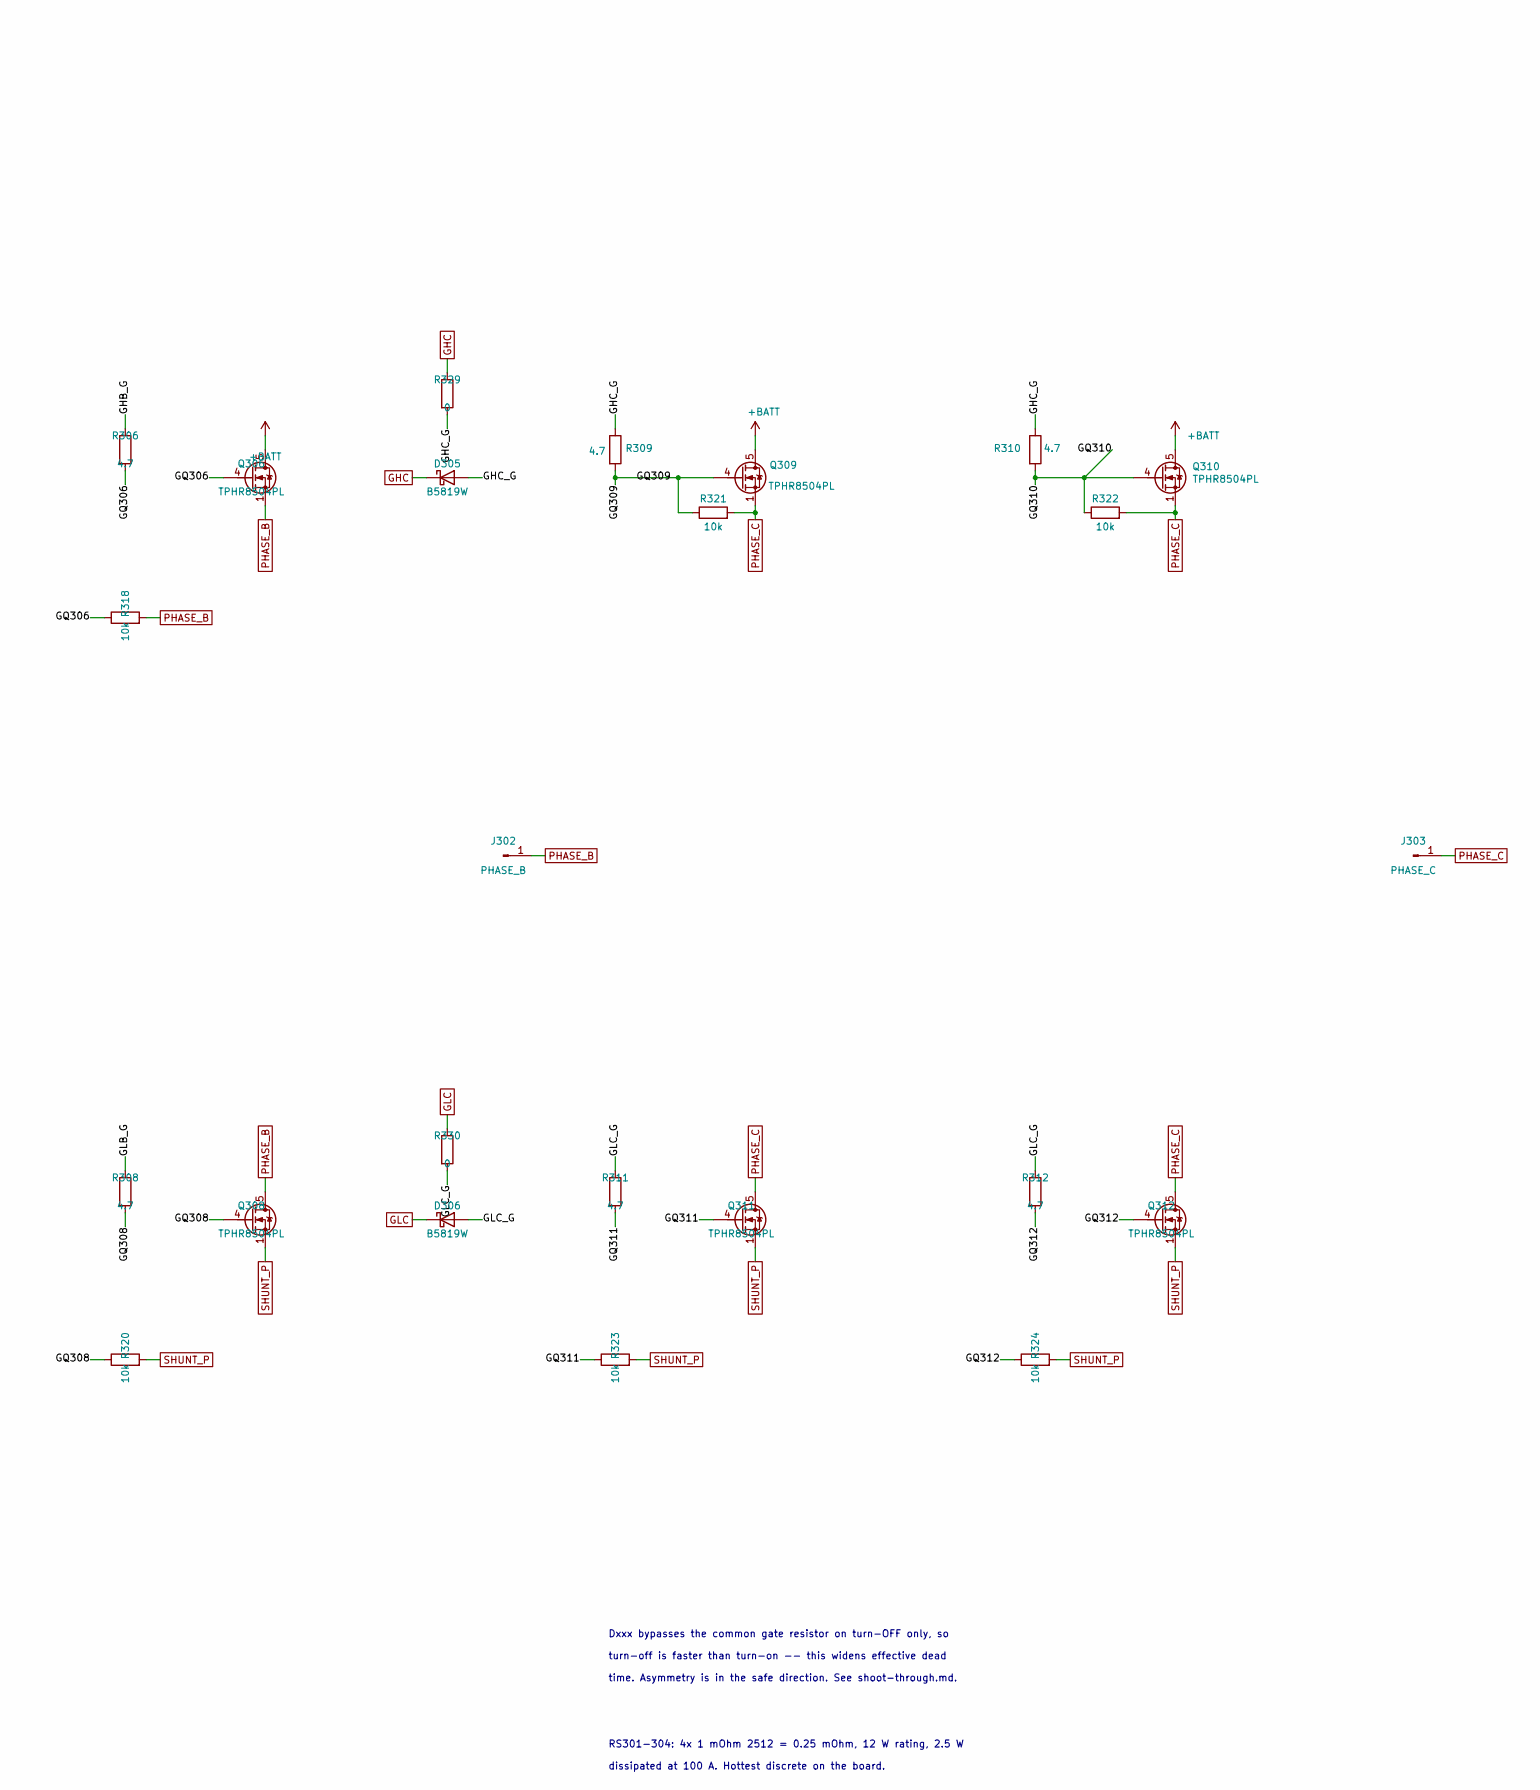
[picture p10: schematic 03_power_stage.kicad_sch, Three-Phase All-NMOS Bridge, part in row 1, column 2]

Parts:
D301, D302, D303, D304, D305, D306: B5819W; D_SOD-123; MPN B5819W SL; LCSC C8598
J301: PHASE_A; HighCurrentTerminal_8AWG
J302: PHASE_B; HighCurrentTerminal_8AWG
J303: PHASE_C; HighCurrentTerminal_8AWG
Q301, Q302, Q303, Q304, Q305, Q306, Q307, Q308, Q309, Q310, Q311, Q312: TPHR8504PL; PQFN-8-EP_6x5mm_P1.27mm_Generic; MPN TPHR8504PL,L1Q(M; LCSC C5331611
R301, R302, R303, R304, R305, R306, R307, R308, R309, R310, R311, R312: 4.7; R_0805_2012Metric; MPN FRC0805F4R70TS; LCSC C2933459
R313, R314, R315, R316, R317, R318, R319, R320, R321, R322, R323, R324: 10k; R_0603_1608Metric; MPN FRC0603F1002TS; LCSC C2906982
R325, R326, R327, R328, R329, R330: 0; R_0603_1608Metric; MPN RCA030RLF; LCSC C22356631
RS301, RS302, RS303, RS304: 1m; R_2512_6332Metric; MPN HoJLR2512-3W-1mR-1%; LCSC C2903470

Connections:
+BATT: Q301.5 (D), Q302.5 (D), Q305.5 (D), Q306.5 (D), Q309.5 (D), Q310.5 (D); also elsewhere on the board
/Power Stage/GHA_G: D301.2 (A), R301.1, R302.1, R325.2
/Power Stage/GHB_G: D303.2 (A), R305.1, R306.1, R327.2
/Power Stage/GHC_G: D305.2 (A), R309.1, R310.1, R329.2
/Power Stage/GLA_G: D302.2 (A), R303.1, R304.1, R326.2
/Power Stage/GLB_G: D304.2 (A), R307.1, R308.1, R328.2
/Power Stage/GLC_G: D306.2 (A), R311.1, R312.1, R330.2
/Power Stage/GQ301: Q301.4 (G), R301.2, R313.1
/Power Stage/GQ302: Q302.4 (G), R302.2, R314.1
/Power Stage/GQ303: Q303.4 (G), R303.2, R315.1
/Power Stage/GQ304: Q304.4 (G), R304.2, R316.1
/Power Stage/GQ305: Q305.4 (G), R305.2, R317.1
/Power Stage/GQ306: Q306.4 (G), R306.2, R318.1
/Power Stage/GQ307: Q307.4 (G), R307.2, R319.1
/Power Stage/GQ308: Q308.4 (G), R308.2, R320.1
/Power Stage/GQ309: Q309.4 (G), R309.2, R321.1
/Power Stage/GQ310: Q310.4 (G), R310.2, R322.1
/Power Stage/GQ311: Q311.4 (G), R311.2, R323.1
/Power Stage/GQ312: Q312.4 (G), R312.2, R324.1
GHA: D301.1 (K), R325.1; also elsewhere on the board
GHB: D303.1 (K), R327.1; also elsewhere on the board
GHC: D305.1 (K), R329.1; also elsewhere on the board
GLA: D302.1 (K), R326.1; also elsewhere on the board
GLB: D304.1 (K), R328.1; also elsewhere on the board
GLC: D306.1 (K), R330.1; also elsewhere on the board
GND: RS301.2, RS302.2, RS303.2, RS304.2; also elsewhere on the board
PHASE_A: J301.1, Q301.1 (S), Q301.2 (S), Q301.3 (S), Q302.1 (S), Q302.2 (S), Q302.3 (S), Q303.5 (D), Q304.5 (D), R313.2, R314.2; also elsewhere on the board
PHASE_B: J302.1, Q305.1 (S), Q305.2 (S), Q305.3 (S), Q306.1 (S), Q306.2 (S), Q306.3 (S), Q307.5 (D), Q308.5 (D), R317.2, R318.2; also elsewhere on the board
PHASE_C: J303.1, Q309.1 (S), Q309.2 (S), Q309.3 (S), Q310.1 (S), Q310.2 (S), Q310.3 (S), Q311.5 (D), Q312.5 (D), R321.2, R322.2; also elsewhere on the board
SHUNT_P: Q303.1 (S), Q303.2 (S), Q303.3 (S), Q304.1 (S), Q304.2 (S), Q304.3 (S), Q307.1 (S), Q307.2 (S), Q307.3 (S), Q308.1 (S), Q308.2 (S), Q308.3 (S), Q311.1 (S), Q311.2 (S), Q311.3 (S), Q312.1 (S), Q312.2 (S), Q312.3 (S), R315.2, R316.2, R319.2, R320.2, R323.2, R324.2, RS301.1, RS302.1, RS303.1, RS304.1; also elsewhere on the board

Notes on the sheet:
and oscillate -- separate resistors de-Q that loop. This is
time. Asymmetry is in the safe direction. See shoot-through.md.
turn-off is faster than turn-on -- this widens effective dead
RS301-304: 4x 1 mOhm 2512 = 0.25 mOhm, 12 W rating, 2.5 W
TPHR8504PL 40 V / 0.85 mOhm max. 40 V on a 12.6 V bus is
directly together resonate through their package inductance
mandatory for paralleled FETs, not optional.
Every FET also has a 10k gate-source pulldown, so a floating
dissipated at 100 A. Hottest discrete on the board.
03 POWER STAGE - 12x N-channel, 2 per switch position
deliberate: a 150 A edge into ~5 nH of loop inductance adds
Dxxx bypasses the common gate resistor on turn-OFF only, so
EVERY FET has its OWN series gate resistor. Two gates tied
7.5 V of overshoot and real layouts do worse.
gate cannot be turned on through Cgd by drain dv/dt.

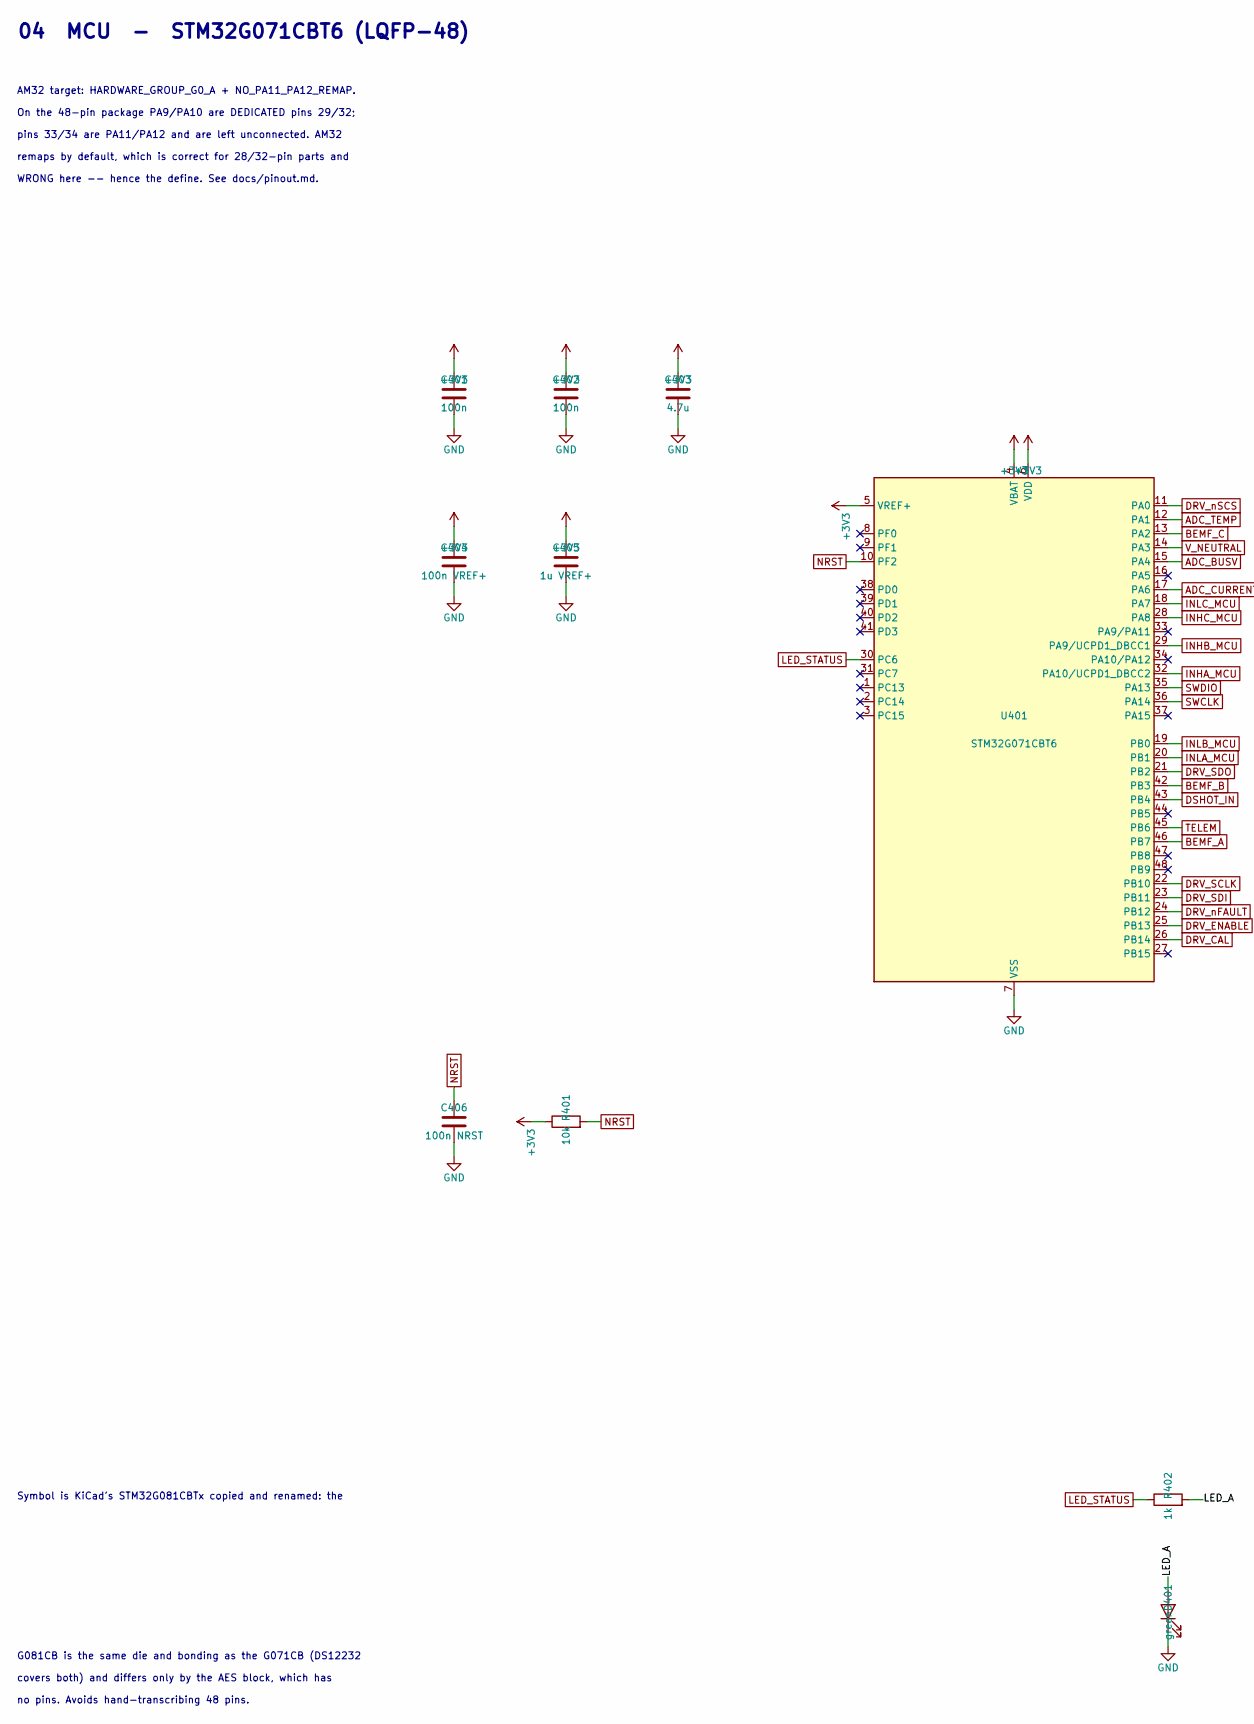
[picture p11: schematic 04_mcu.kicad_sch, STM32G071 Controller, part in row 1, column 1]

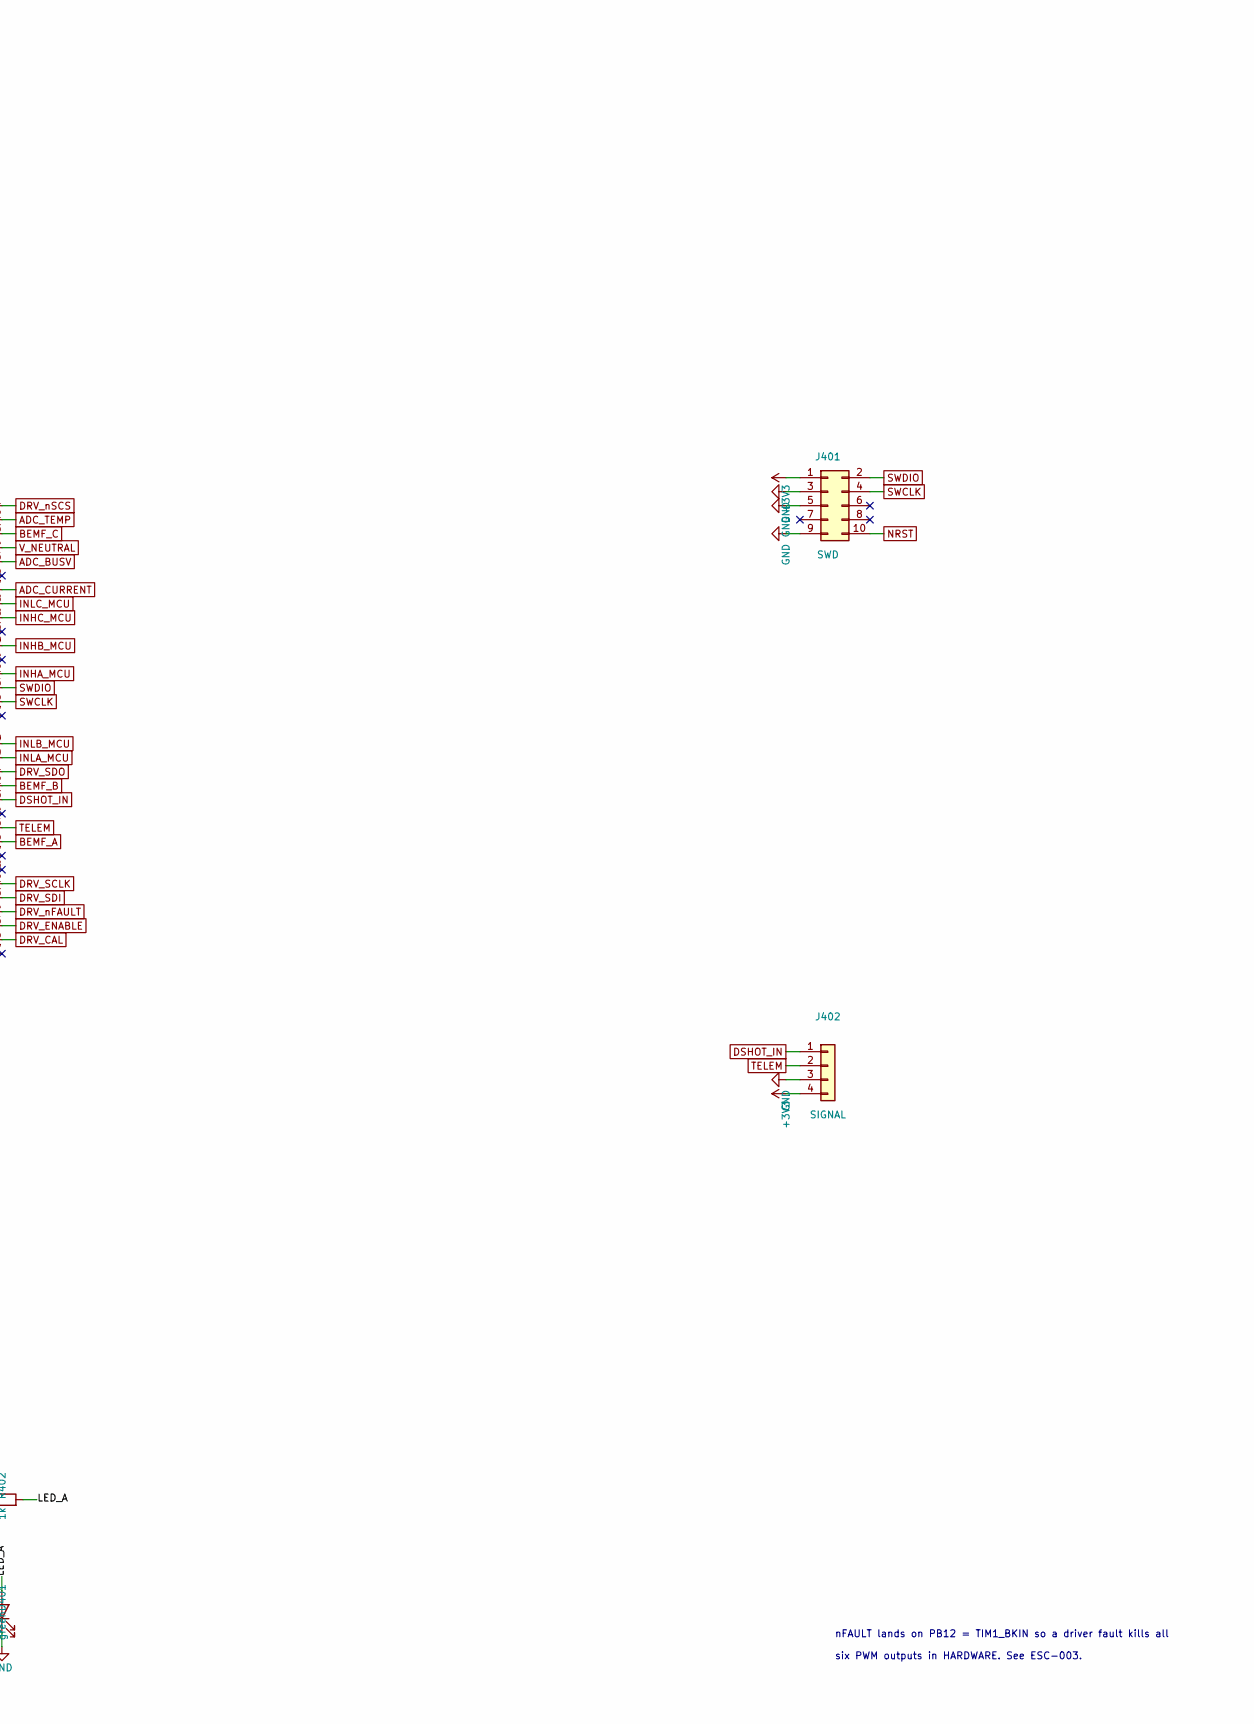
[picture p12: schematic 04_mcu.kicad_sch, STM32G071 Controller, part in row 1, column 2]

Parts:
C401, C402: 100n; C_0603_1608Metric; MPN CC0603KRX7R9BB104; LCSC C14663
C403: 4.7u; C_0805_2012Metric; MPN CL21B475KAFNNNE; LCSC C98195
C404: 100n VREF+; C_0603_1608Metric; MPN CC0603KRX7R9BB104; LCSC C14663
C405: 1u VREF+; C_0603_1608Metric; MPN CL10B105KA8NNNC; LCSC C29936
C406: 100n NRST; C_0603_1608Metric; MPN CC0603KRX7R9BB104; LCSC C14663
D401: green; LED_0603_1608Metric; MPN XL-1608UGC-04; LCSC C965804
J401: SWD; PinHeader_2x05_P1.27mm_Vertical
J402: SIGNAL; PinHeader_1x04_P2.54mm_Vertical
R401: 10k; R_0603_1608Metric; MPN FRC0603F1002TS; LCSC C2906982
R402: 1k; R_0603_1608Metric; MPN FRC0603F1001TS; LCSC C2907002
U401: STM32G071CBT6; LQFP-48_7x7mm_P0.5mm; MPN STM32G071CBT6; LCSC C432212

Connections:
+3V3: C401.1, C402.1, C403.1, C404.1, C405.1, J401.1, J402.4, R401.1, U401.4 (VBAT), U401.5 (VREF+), U401.6 (VDD); also elsewhere on the board
/MCU/LED_A: D401.2 (A), R402.2
ADC_BUSV: U401.15 (PA4); also elsewhere on the board
ADC_CURRENT: U401.17 (PA6); also elsewhere on the board
ADC_TEMP: U401.12 (PA1); also elsewhere on the board
BEMF_A: U401.46 (PB7); also elsewhere on the board
BEMF_B: U401.42 (PB3); also elsewhere on the board
BEMF_C: U401.13 (PA2); also elsewhere on the board
DRV_CAL: U401.26 (PB14); also elsewhere on the board
DRV_ENABLE: U401.25 (PB13); also elsewhere on the board
DRV_SCLK: U401.22 (PB10); also elsewhere on the board
DRV_SDI: U401.23 (PB11); also elsewhere on the board
DRV_SDO: U401.21 (PB2); also elsewhere on the board
DRV_nFAULT: U401.24 (PB12); also elsewhere on the board
DRV_nSCS: U401.11 (PA0); also elsewhere on the board
DSHOT_IN: J402.1, U401.43 (PB4)
GND: C401.2, C402.2, C403.2, C404.2, C405.2, C406.2, D401.1 (K), J401.3, J401.5, J401.9, J402.3, U401.7 (VSS); also elsewhere on the board
INHA_MCU: U401.32 (PA10/UCPD1_DBCC2); also elsewhere on the board
INHB_MCU: U401.29 (PA9/UCPD1_DBCC1); also elsewhere on the board
INHC_MCU: U401.28 (PA8); also elsewhere on the board
INLA_MCU: U401.20 (PB1); also elsewhere on the board
INLB_MCU: U401.19 (PB0); also elsewhere on the board
INLC_MCU: U401.18 (PA7); also elsewhere on the board
LED_STATUS: R402.1, U401.30 (PC6)
NRST: C406.1, J401.10, R401.2, U401.10 (PF2)
SWCLK: J401.4, U401.36 (PA14)
SWDIO: J401.2, U401.35 (PA13)
TELEM: J402.2, U401.45 (PB6)
V_NEUTRAL: U401.14 (PA3); also elsewhere on the board

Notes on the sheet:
no pins. Avoids hand-transcribing 48 pins.
pins 33/34 are PA11/PA12 and are left unconnected. AM32
WRONG here -- hence the define. See docs/pinout.md.
04 MCU - STM32G071CBT6 (LQFP-48)
nFAULT lands on PB12 = TIM1_BKIN so a driver fault kills all
remaps by default, which is correct for 28/32-pin parts and
covers both) and differs only by the AES block, which has
G081CB is the same die and bonding as the G071CB (DS12232
six PWM outputs in HARDWARE. See ESC-003.
On the 48-pin package PA9/PA10 are DEDICATED pins 29/32;
AM32 target: HARDWARE_GROUP_G0_A + NO_PA11_PA12_REMAP.
Symbol is KiCad's STM32G081CBTx copied and renamed: the

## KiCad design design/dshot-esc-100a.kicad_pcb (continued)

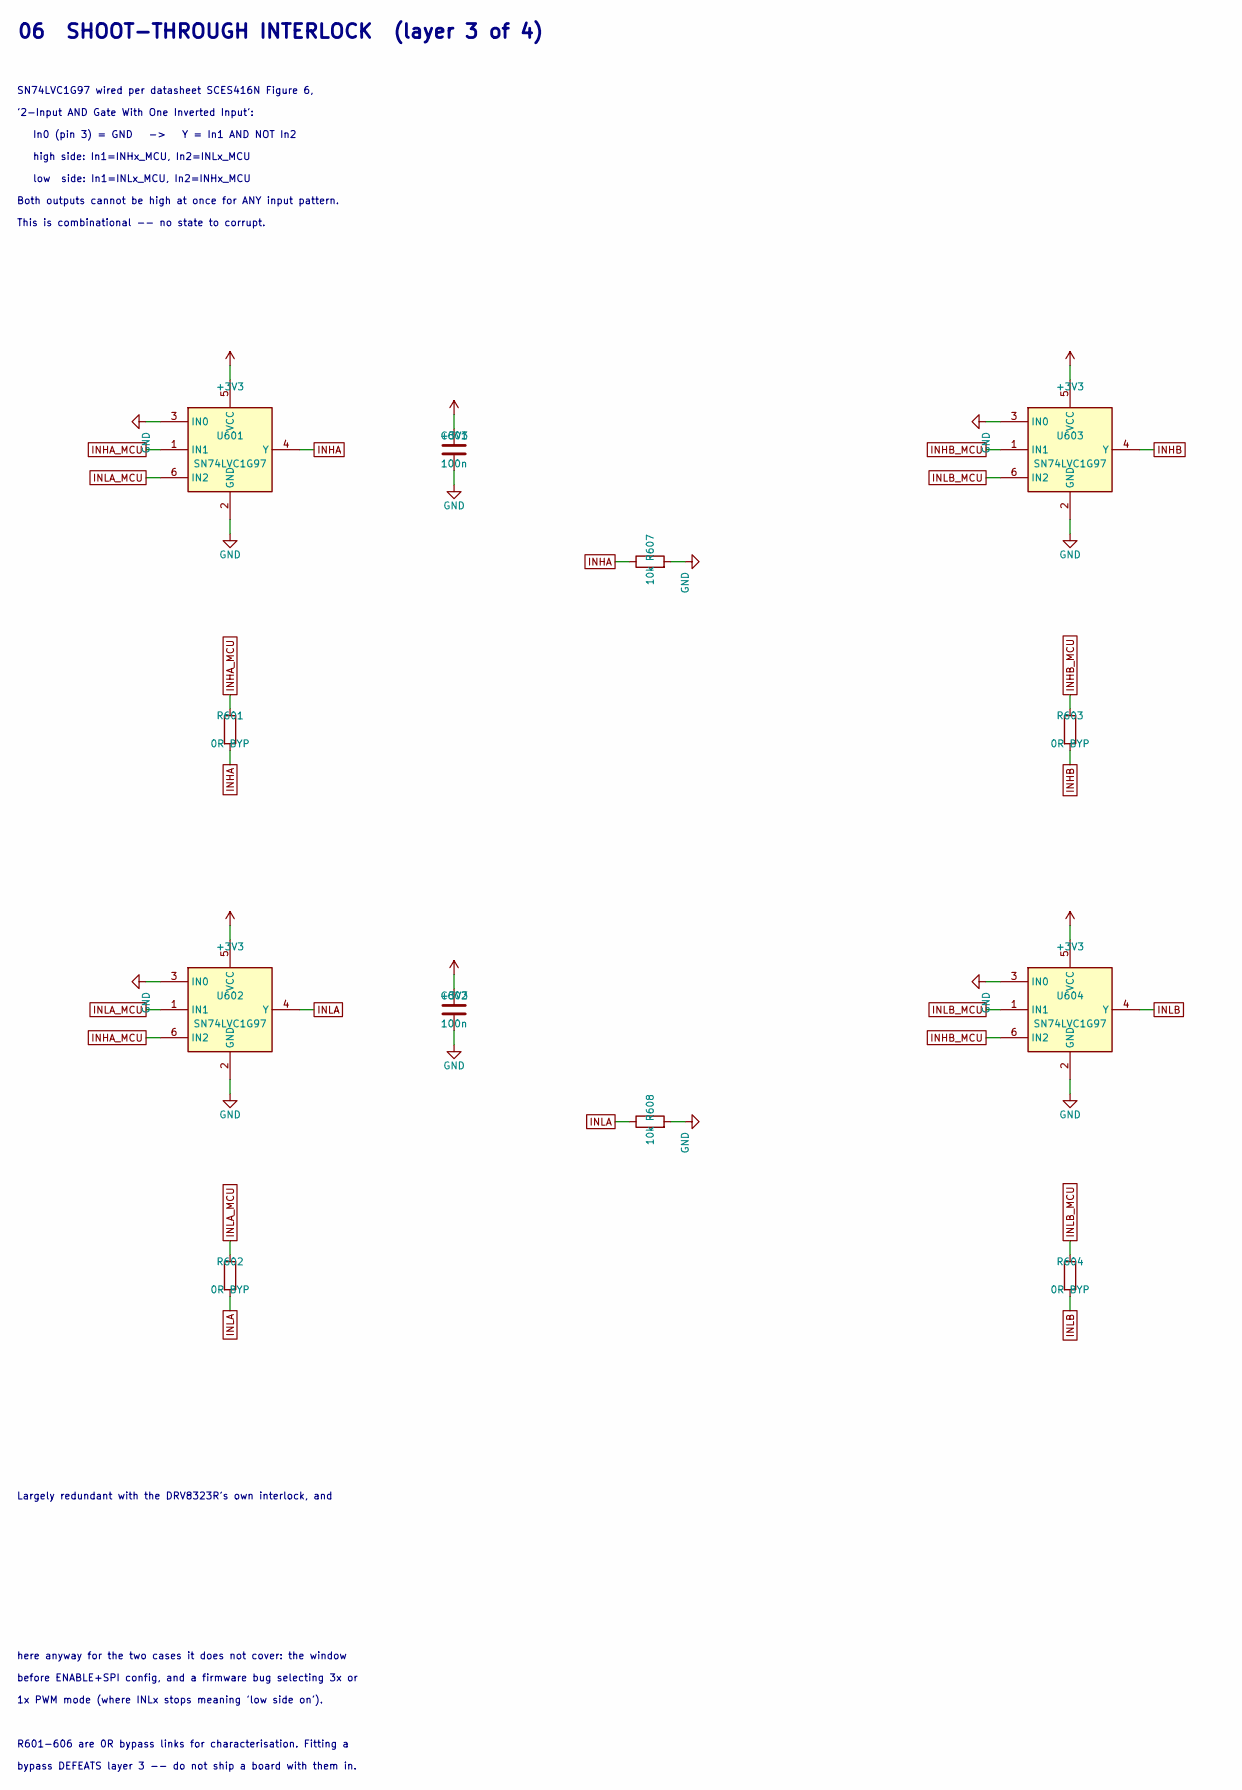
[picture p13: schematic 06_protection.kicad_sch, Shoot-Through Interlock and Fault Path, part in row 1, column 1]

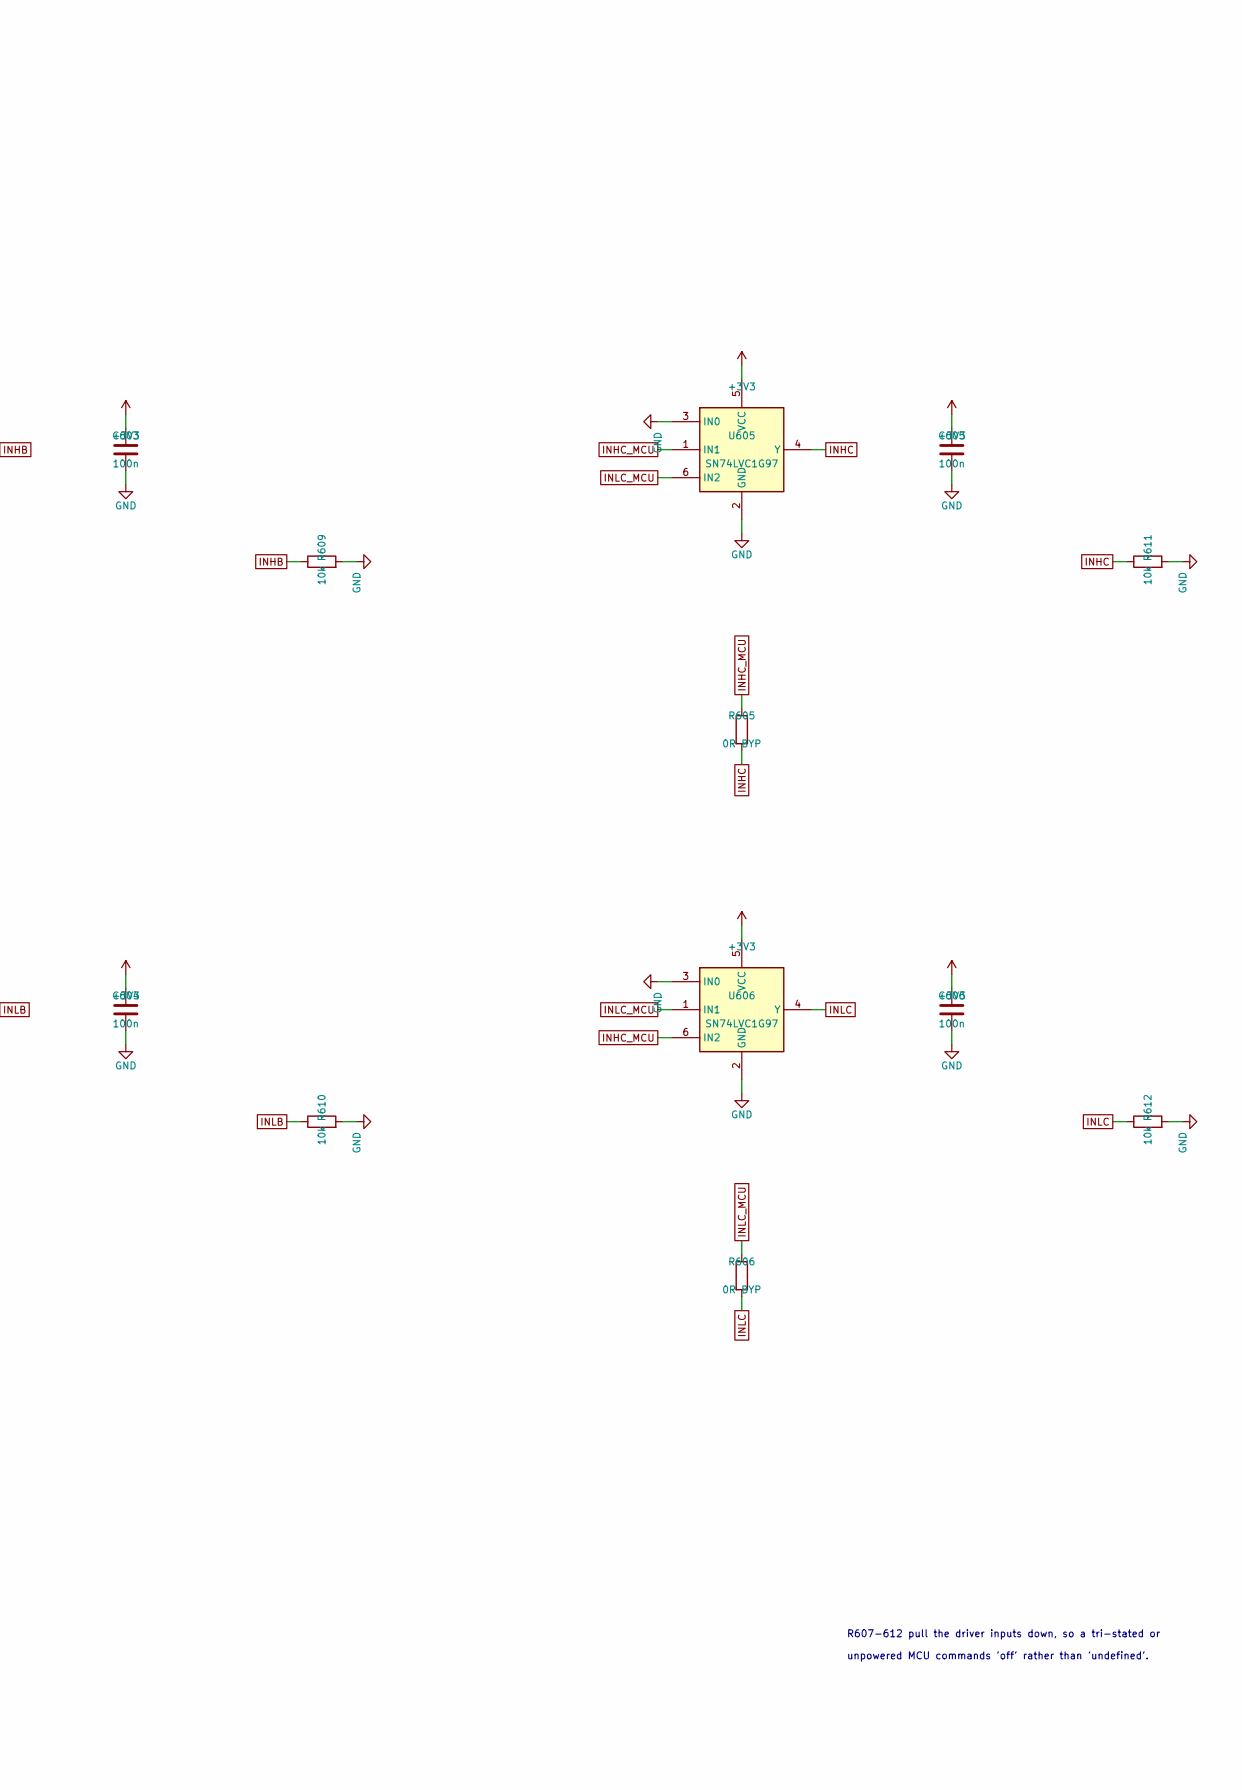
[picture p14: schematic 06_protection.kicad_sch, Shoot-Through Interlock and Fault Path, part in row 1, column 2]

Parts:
C601, C602, C603, C604, C605, C606: 100n; C_0603_1608Metric; MPN CC0603KRX7R9BB104; LCSC C14663
R601, R602, R603, R604, R605, R606: 0R BYP; R_0603_1608Metric; MPN RCA030RLF; LCSC C22356631
R607, R608, R609, R610, R611, R612: 10k; R_0603_1608Metric; MPN FRC0603F1002TS; LCSC C2906982
U601, U602, U603, U604, U605, U606: SN74LVC1G97; SOT-23-6; MPN SN74LVC1G97DBVR; LCSC C128411

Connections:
+3V3: C601.1, C602.1, C603.1, C604.1, C605.1, C606.1, U601.5 (VCC), U602.5 (VCC), U603.5 (VCC), U604.5 (VCC), U605.5 (VCC), U606.5 (VCC); also elsewhere on the board
GND: C601.2, C602.2, C603.2, C604.2, C605.2, C606.2, R607.2, R608.2, R609.2, R610.2, R611.2, R612.2, U601.2 (GND), U601.3 (IN0), U602.2 (GND), U602.3 (IN0), U603.2 (GND), U603.3 (IN0), U604.2 (GND), U604.3 (IN0), U605.2 (GND), U605.3 (IN0), U606.2 (GND), U606.3 (IN0); also elsewhere on the board
INHA: R601.2, R607.1, U601.4 (Y); also elsewhere on the board
INHA_MCU: R601.1, U601.1 (IN1), U602.6 (IN2); also elsewhere on the board
INHB: R603.2, R609.1, U603.4 (Y); also elsewhere on the board
INHB_MCU: R603.1, U603.1 (IN1), U604.6 (IN2); also elsewhere on the board
INHC: R605.2, R611.1, U605.4 (Y); also elsewhere on the board
INHC_MCU: R605.1, U605.1 (IN1), U606.6 (IN2); also elsewhere on the board
INLA: R602.2, R608.1, U602.4 (Y); also elsewhere on the board
INLA_MCU: R602.1, U601.6 (IN2), U602.1 (IN1); also elsewhere on the board
INLB: R604.2, R610.1, U604.4 (Y); also elsewhere on the board
INLB_MCU: R604.1, U603.6 (IN2), U604.1 (IN1); also elsewhere on the board
INLC: R606.2, R612.1, U606.4 (Y); also elsewhere on the board
INLC_MCU: R606.1, U605.6 (IN2), U606.1 (IN1); also elsewhere on the board

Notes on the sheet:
high side: In1=INHx_MCU, In2=INLx_MCU
low side: In1=INLx_MCU, In2=INHx_MCU
before ENABLE+SPI config, and a firmware bug selecting 3x or
Largely redundant with the DRV8323R's own interlock, and
R601-606 are 0R bypass links for characterisation. Fitting a
06 SHOOT-THROUGH INTERLOCK (layer 3 of 4)
SN74LVC1G97 wired per datasheet SCES416N Figure 6,
bypass DEFEATS layer 3 -- do not ship a board with them in.
'2-Input AND Gate With One Inverted Input':
1x PWM mode (where INLx stops meaning 'low side on').
This is combinational -- no state to corrupt.
Both outputs cannot be high at once for ANY input pattern.
here anyway for the two cases it does not cover: the window
unpowered MCU commands 'off' rather than 'undefined'.
In0 (pin 3) = GND -> Y = In1 AND NOT In2
R607-612 pull the driver inputs down, so a tri-stated or

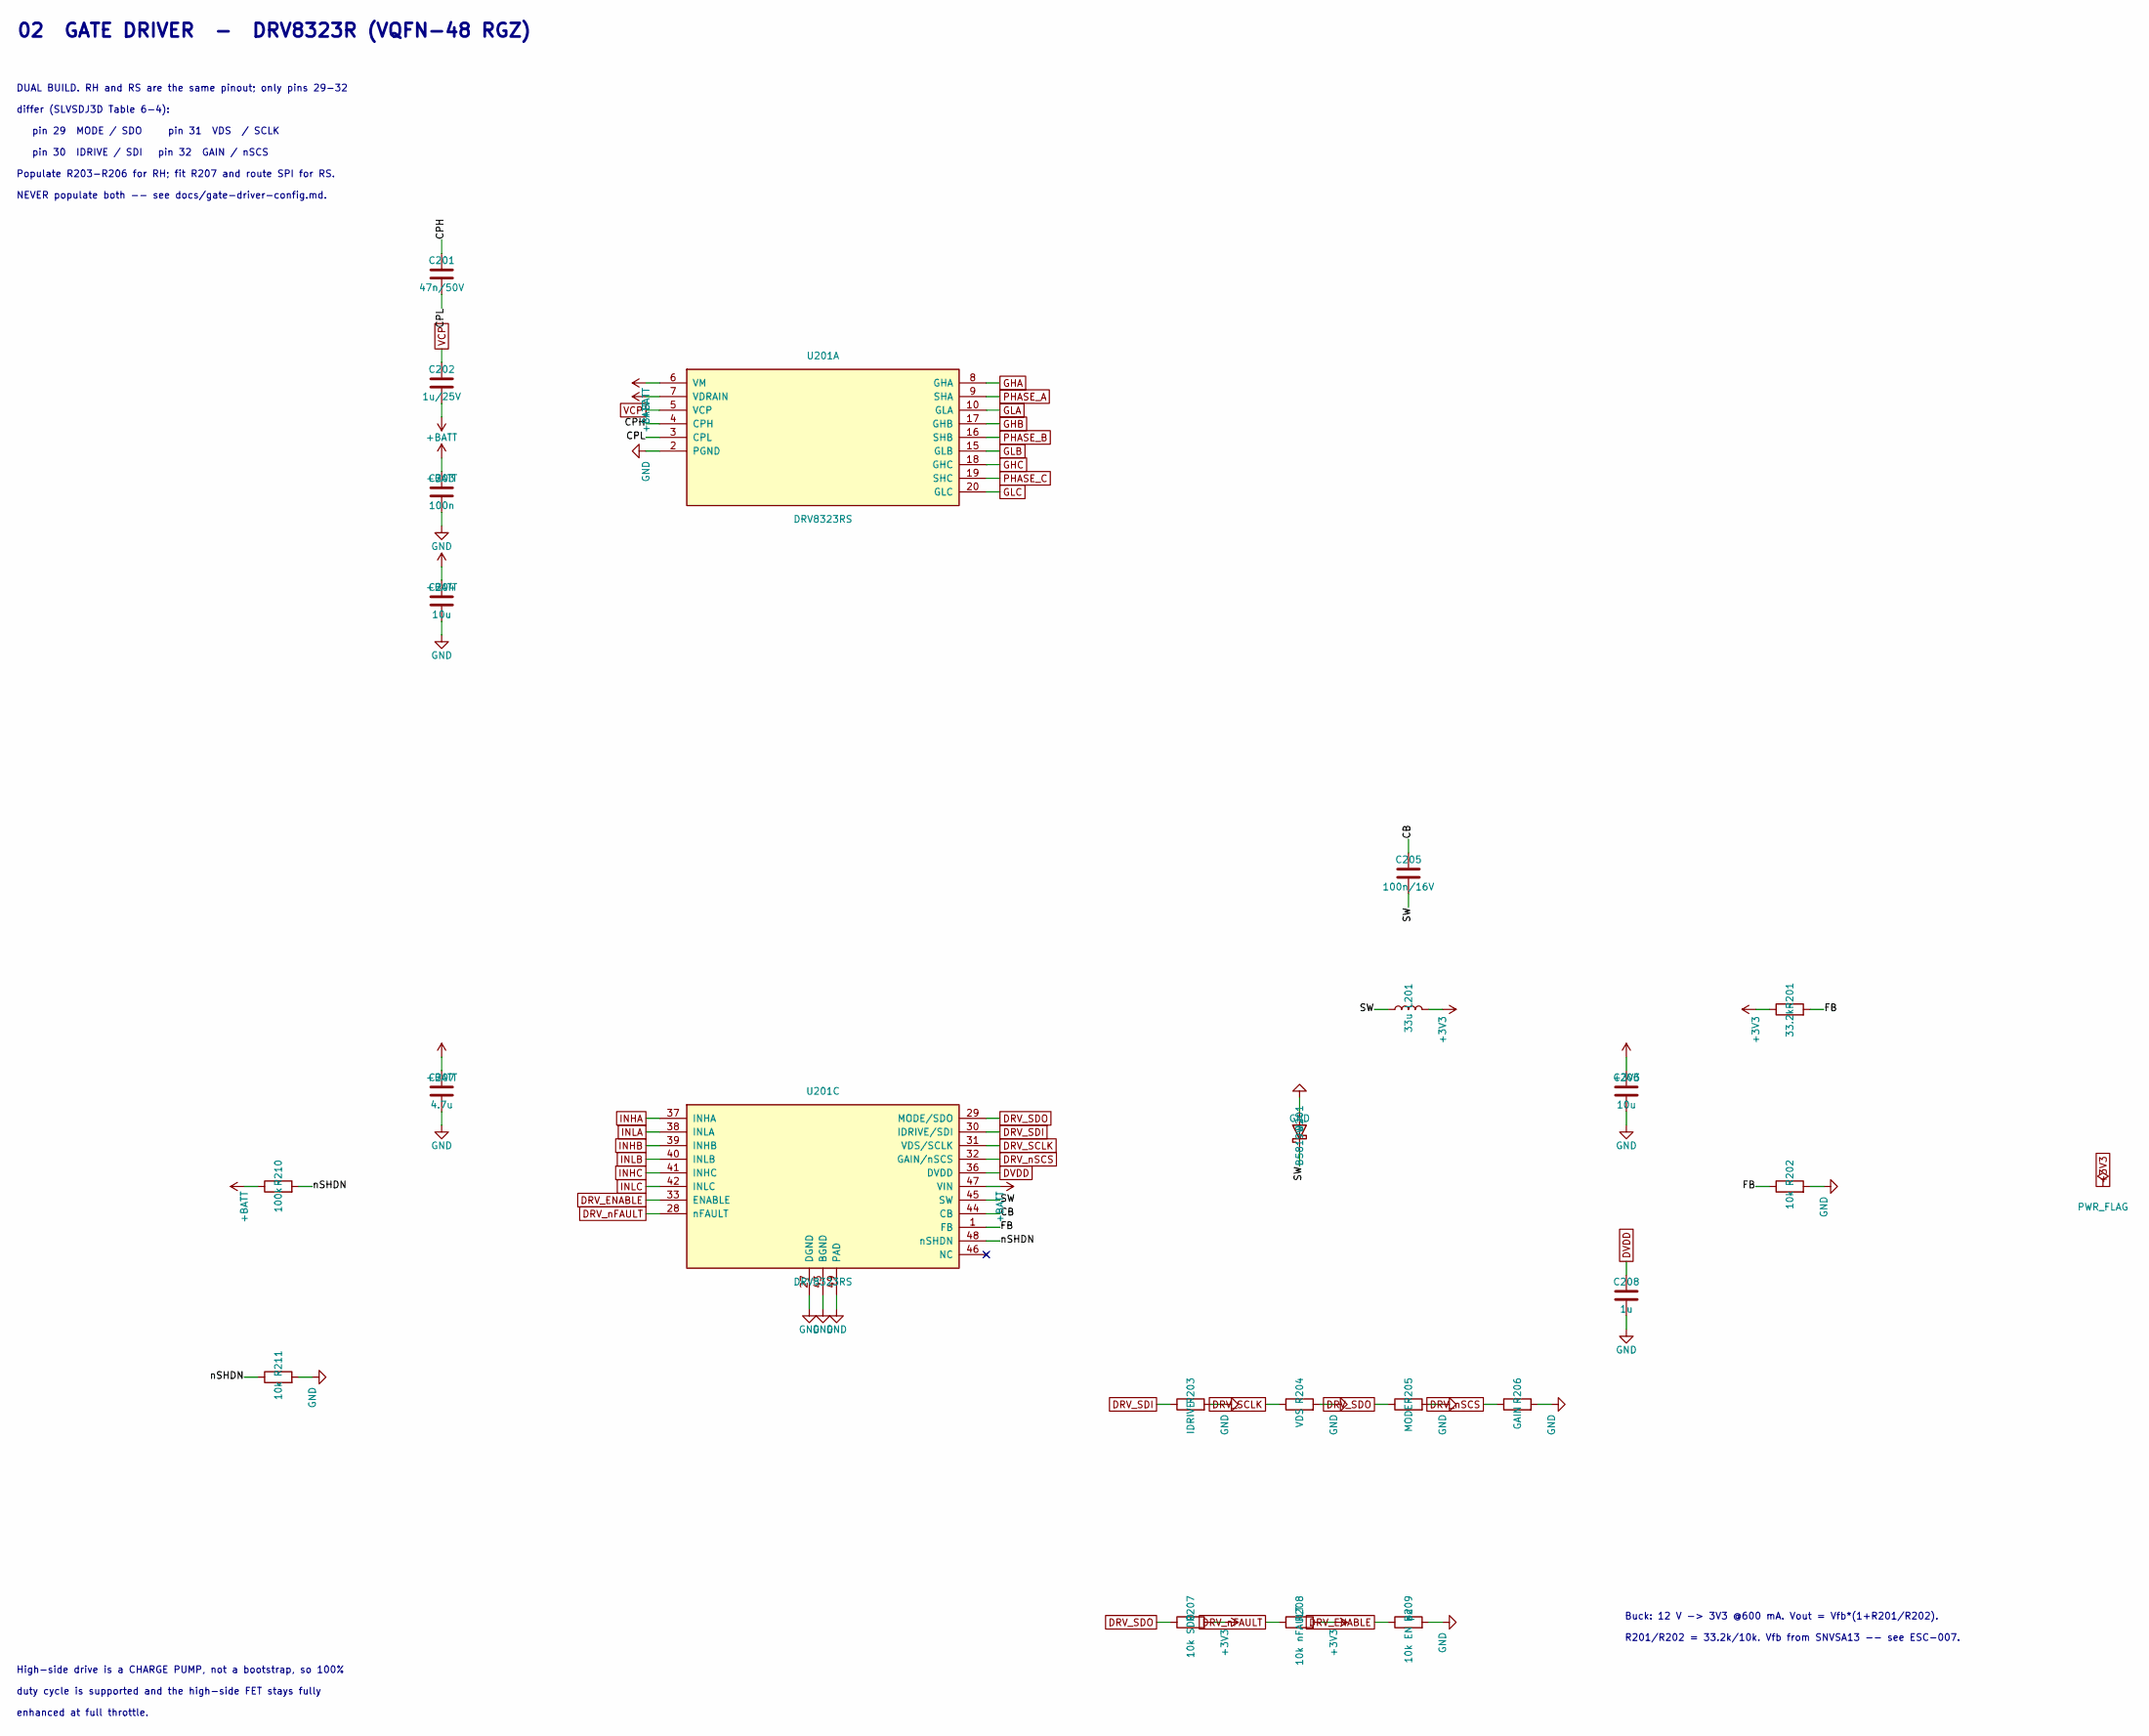
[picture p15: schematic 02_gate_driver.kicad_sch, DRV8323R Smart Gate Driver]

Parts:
C201: 47n/50V; C_0603_1608Metric; MPN CL10B473KB8NNNC; LCSC C1622
C202: 1u/25V; C_0603_1608Metric; MPN CL10B105KA8NNNC; LCSC C29936
C203: 100n; C_0603_1608Metric; MPN CC0603KRX7R9BB104; LCSC C14663
C204, C206: 10u; C_1210_3225Metric; MPN GRM32DR71E106KA12L; LCSC C77100
C205: 100n/16V; C_0603_1608Metric; MPN CC0603KRX7R9BB104; LCSC C14663
C207: 4.7u; C_0805_2012Metric; MPN CL21B475KAFNNNE; LCSC C98195
C208: 1u; C_0603_1608Metric; MPN CL10B105KA8NNNC; LCSC C29936
D201: B5819W; D_SOD-123; MPN B5819W SL; LCSC C8598
L201: 33u; L_7.3x7.3_H3.5; MPN SLS6D38S330MTT; LCSC C364136
R201: 33.2k; R_0603_1608Metric; MPN FRC0603F3322TS; LCSC C2933200
R202, R211: 10k; R_0603_1608Metric; MPN FRC0603F1002TS; LCSC C2906982
R203: IDRIVE; R_0603_1608Metric; MPN FRC0603F1002TS; LCSC C2906982
R204: VDS; R_0603_1608Metric; MPN FRC0603F1002TS; LCSC C2906982
R205: MODE; R_0603_1608Metric; MPN FRC0603F1002TS; LCSC C2906982
R206: GAIN; R_0603_1608Metric; MPN FRC0603F1002TS; LCSC C2906982
R207: 10k SDO; R_0603_1608Metric; MPN FRC0603F1002TS; LCSC C2906982
R208: 10k nFAULT; R_0603_1608Metric; MPN FRC0603F1002TS; LCSC C2906982
R209: 10k EN pd; R_0603_1608Metric; MPN FRC0603F1002TS; LCSC C2906982
R210: 100k; R_0603_1608Metric; MPN 0603WAF1003T5E; LCSC C25803
U201: DRV8323RS; Texas_RGZ0048A_VQFN-48-1EP_7x7mm_P0.5mm_EP5.15x5.15mm; MPN DRV8323RSRGZT; LCSC C2653553

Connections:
+3V3: C206.1, L201.2, R201.1, R207.2, R208.2; also elsewhere on the board
+BATT: C202.2, C203.1, C204.1, C207.1, R210.1, U201.6 (VM), U201.7 (VDRAIN), U201.47 (VIN); also elsewhere on the board
/Gate Driver/CB: C205.1, U201.44 (CB)
/Gate Driver/CPH: C201.1, U201.4 (CPH)
/Gate Driver/CPL: C201.2, U201.3 (CPL)
/Gate Driver/FB: R201.2, R202.1, U201.1 (FB)
/Gate Driver/SW: C205.2, D201.1 (K), L201.1, U201.45 (SW)
/Gate Driver/nSHDN: R210.2, R211.1, U201.48 (nSHDN)
DRV_ENABLE: R209.1, U201.33 (ENABLE); also elsewhere on the board
DRV_SCLK: R204.1, U201.31 (VDS/SCLK); also elsewhere on the board
DRV_SDI: R203.1, U201.30 (IDRIVE/SDI); also elsewhere on the board
DRV_SDO: R205.1, R207.1, U201.29 (MODE/SDO); also elsewhere on the board
DRV_nFAULT: R208.1, U201.28 (nFAULT); also elsewhere on the board
DRV_nSCS: R206.1, U201.32 (GAIN/nSCS); also elsewhere on the board
DVDD: C208.1, U201.36 (DVDD)
GHA: U201.8 (GHA); also elsewhere on the board
GHB: U201.17 (GHB); also elsewhere on the board
GHC: U201.18 (GHC); also elsewhere on the board
GLA: U201.10 (GLA); also elsewhere on the board
GLB: U201.15 (GLB); also elsewhere on the board
GLC: U201.20 (GLC); also elsewhere on the board
GND: C203.2, C204.2, C206.2, C207.2, C208.2, D201.2 (A), R202.2, R203.2, R204.2, R205.2, R206.2, R209.2, R211.2, U201.2 (PGND), U201.27 (DGND), U201.43 (BGND), U201.49 (PAD); also elsewhere on the board
INHA: U201.37 (INHA); also elsewhere on the board
INHB: U201.39 (INHB); also elsewhere on the board
INHC: U201.41 (INHC); also elsewhere on the board
INLA: U201.38 (INLA); also elsewhere on the board
INLB: U201.40 (INLB); also elsewhere on the board
INLC: U201.42 (INLC); also elsewhere on the board
PHASE_A: U201.9 (SHA); also elsewhere on the board
PHASE_B: U201.16 (SHB); also elsewhere on the board
PHASE_C: U201.19 (SHC); also elsewhere on the board
VCP: C202.1, U201.5 (VCP)

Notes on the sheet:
Populate R203-R206 for RH; fit R207 and route SPI for RS.
DUAL BUILD. RH and RS are the same pinout; only pins 29-32
Buck: 12 V -> 3V3 @600 mA. Vout = Vfb*(1+R201/R202).
differ (SLVSDJ3D Table 6-4):
02 GATE DRIVER - DRV8323R (VQFN-48 RGZ)
pin 29 MODE / SDO pin 31 VDS / SCLK
R201/R202 = 33.2k/10k. Vfb from SNVSA13 -- see ESC-007.
enhanced at full throttle.
NEVER populate both -- see docs/gate-driver-config.md.
duty cycle is supported and the high-side FET stays fully
High-side drive is a CHARGE PUMP, not a bootstrap, so 100%
pin 30 IDRIVE / SDI pin 32 GAIN / nSCS

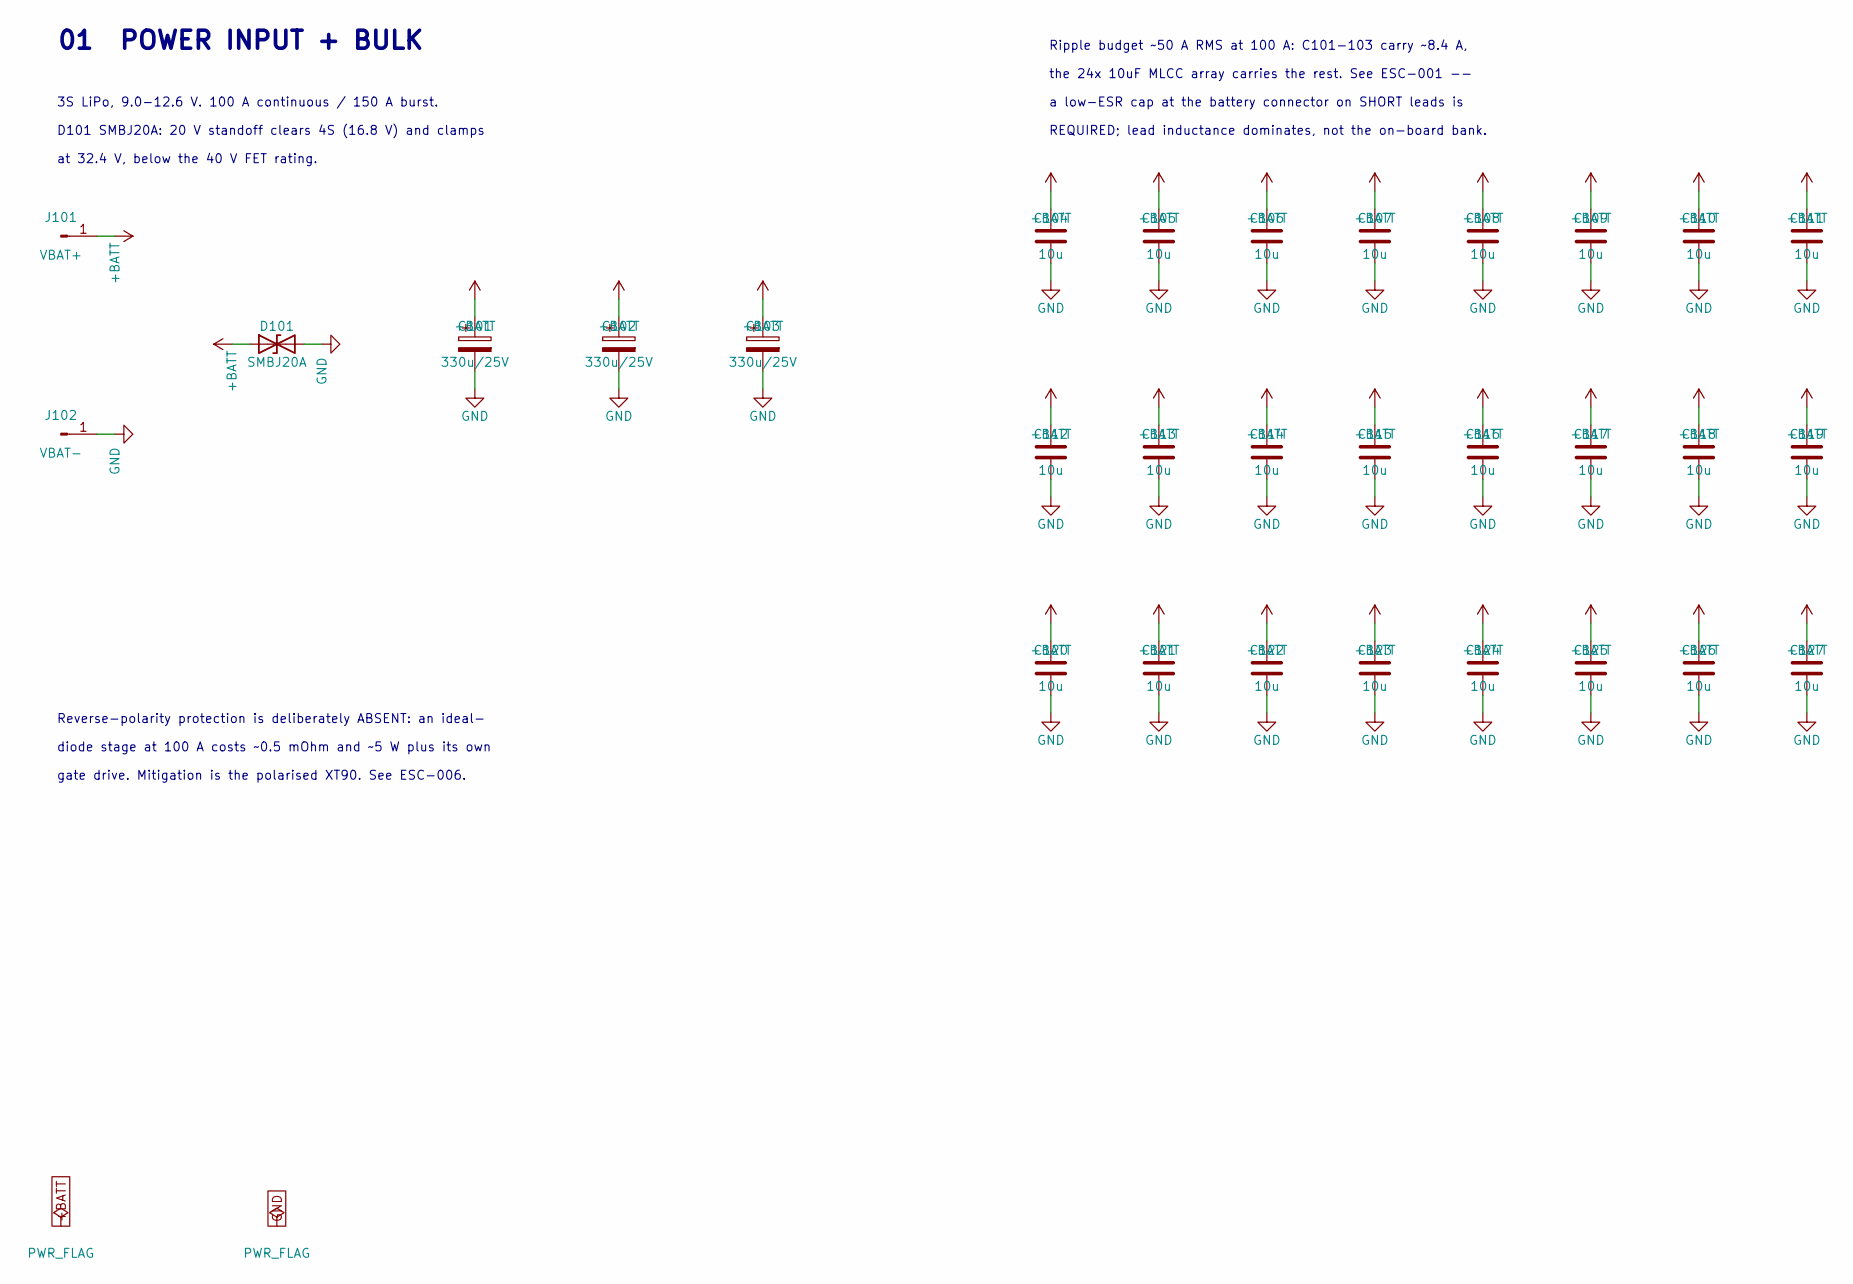
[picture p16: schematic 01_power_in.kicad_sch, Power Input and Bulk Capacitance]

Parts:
C101, C102, C103: 330u/25V; CP_Radial_D8.0mm_P3.50mm; MPN SPZ1EM331F11O00R; LCSC C160677
C104, C105, C106, C107, C108, C109, C110, C111, C112, C113, C114, C115, C116, C117, C118, C119, C120, C121, C122, C123, C124, C125, C126, C127: 10u; C_1210_3225Metric; MPN GRM32DR71E106KA12L; LCSC C77100
D101: SMBJ20A; D_SMB; MPN SMBJ20A; LCSC C364296
J101: VBAT+; HighCurrentTerminal_8AWG
J102: VBAT-; HighCurrentTerminal_8AWG

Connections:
+BATT: C101.1, C102.1, C103.1, C104.1, C105.1, C106.1, C107.1, C108.1, C109.1, C110.1, C111.1, C112.1, C113.1, C114.1, C115.1, C116.1, C117.1, C118.1, C119.1, C120.1, C121.1, C122.1, C123.1, C124.1, C125.1, C126.1, C127.1, D101.1 (A1), J101.1; also elsewhere on the board
GND: C101.2, C102.2, C103.2, C104.2, C105.2, C106.2, C107.2, C108.2, C109.2, C110.2, C111.2, C112.2, C113.2, C114.2, C115.2, C116.2, C117.2, C118.2, C119.2, C120.2, C121.2, C122.2, C123.2, C124.2, C125.2, C126.2, C127.2, D101.2 (A2), J102.1; also elsewhere on the board

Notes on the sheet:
Reverse-polarity protection is deliberately ABSENT: an ideal-
gate drive. Mitigation is the polarised XT90. See ESC-006.
at 32.4 V, below the 40 V FET rating.
a low-ESR cap at the battery connector on SHORT leads is
3S LiPo, 9.0-12.6 V. 100 A continuous / 150 A burst.
01 POWER INPUT + BULK
REQUIRED; lead inductance dominates, not the on-board bank.
Ripple budget ~50 A RMS at 100 A: C101-103 carry ~8.4 A,
diode stage at 100 A costs ~0.5 mOhm and ~5 W plus its own
the 24x 10uF MLCC array carries the rest. See ESC-001 --
D101 SMBJ20A: 20 V standoff clears 4S (16.8 V) and clamps

Board: 4 copper layers, 160 parts (53 on the bottom side), 72 nets, no tracks yet.

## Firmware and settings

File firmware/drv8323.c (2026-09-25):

/* DRV8323RS configuration for dshot-esc-100a.
 *
 * AM32 ships no SPI gate-driver support, so this is additive: drop it in
 * Mcu/g071/Src/ and call drv8323_init() from main() after
 * initCorePeripherals() and before the motor is enabled.
 *
 * SPI is BIT-BANGED, deliberately. This is a one-shot boot transaction
 * with no throughput requirement, and bit-banging removes all dependence
 * on the STM32G0 alternate-function table for PB10/PB11/PB2, which has
 * not been verified against DS12232 (issue ESC-002). Hardware SPI2 stays
 * available later -- the pins were chosen to be SPI2-capable.
 *
 * Frame format (SLVSDJ3D section 8.5.1): 16 bits, MSB first.
 *   bit 15    : 1 = read, 0 = write
 *   bits 14-11: register address
 *   bits 10-0 : data
 * Data is captured on the FALLING edge of SCLK; SDO shifts out on the
 * rising edge. nSCS must go high between frames to latch.
 *
 * Register values are derived in docs/gate-driver-config.md.
 */

#include "main.h"
#include "stm32g0xx_ll_gpio.h"

/* ---- pin map (see docs/pinout.md) ---- */
#define DRV_SCLK_PORT   GPIOB
#define DRV_SCLK_PIN    LL_GPIO_PIN_10
#define DRV_SDI_PORT    GPIOB
#define DRV_SDI_PIN     LL_GPIO_PIN_11
#define DRV_SDO_PORT    GPIOB
#define DRV_SDO_PIN     LL_GPIO_PIN_2
#define DRV_NSCS_PORT   GPIOA
#define DRV_NSCS_PIN    LL_GPIO_PIN_0
#define DRV_EN_PORT     GPIOB
#define DRV_EN_PIN      LL_GPIO_PIN_13

/* ---- register addresses ---- */
#define REG_FAULT1      0x00
#define REG_FAULT2      0x01
#define REG_DRIVER_CTRL 0x02
#define REG_GATE_HS     0x03
#define REG_GATE_LS     0x04
#define REG_OCP_CTRL    0x05
#define REG_CSA_CTRL    0x06

/* ---- values: see docs/gate-driver-config.md for the bit-by-bit tables ---- */
#define VAL_DRIVER_CTRL 0x080u  /* 6x PWM, OTW reported on nFAULT          */
#define VAL_GATE_HS     0x39Cu  /* unlocked, 330 mA source / 1140 mA sink  */
#define VAL_GATE_LS     0x79Cu  /* CBC, TDRIVE 4us, same IDRIVE as HS      */
#define VAL_OCP_CTRL    0x151u  /* 100 ns dead time, retry, 4us, VDS 0.13V */
#define VAL_CSA_CTRL    0x0C3u  /* unidirectional, 40 V/V, SPx input       */

static void drv_delay(void)
{
    /* ~1 us at 64 MHz -- well inside the DRV8323's 100 ns SCLK minimum,
     * and slow enough that trace length is irrelevant. */
    for (volatile int i = 0; i < 16; i++) { __NOP(); }
}

static uint16_t drv8323_transfer(uint16_t frame)
{
    uint16_t in = 0;

    LL_GPIO_ResetOutputPin(DRV_SCLK_PORT, DRV_SCLK_PIN);
    LL_GPIO_ResetOutputPin(DRV_NSCS_PORT, DRV_NSCS_PIN);
    drv_delay();

    for (int bit = 15; bit >= 0; bit--) {
        if (frame & (1u << bit)) {
            LL_GPIO_SetOutputPin(DRV_SDI_PORT, DRV_SDI_PIN);
        } else {
            LL_GPIO_ResetOutputPin(DRV_SDI_PORT, DRV_SDI_PIN);
        }
        drv_delay();

        /* rising edge: DRV shifts SDO out */
        LL_GPIO_SetOutputPin(DRV_SCLK_PORT, DRV_SCLK_PIN);
        drv_delay();

        in <<= 1;
        if (LL_GPIO_IsInputPinSet(DRV_SDO_PORT, DRV_SDO_PIN)) {
            in |= 1u;
        }

        /* falling edge: DRV captures SDI */
        LL_GPIO_ResetOutputPin(DRV_SCLK_PORT, DRV_SCLK_PIN);
        drv_delay();
    }

    LL_GPIO_SetOutputPin(DRV_NSCS_PORT, DRV_NSCS_PIN);
    drv_delay();
    return in & 0x7FFu;
}

static void drv8323_write(uint8_t addr, uint16_t data)
{
    drv8323_transfer((uint16_t)((addr & 0x0Fu) << 11) | (data & 0x7FFu));
}

uint16_t drv8323_read(uint8_t addr)
{
    return drv8323_transfer(0x8000u | (uint16_t)((addr & 0x0Fu) << 11));
}

static void drv8323_gpio_init(void)
{
    LL_GPIO_InitTypeDef io = { 0 };
    LL_IOP_GRP1_EnableClock(LL_IOP_GRP1_PERIPH_GPIOA);
    LL_IOP_GRP1_EnableClock(LL_IOP_GRP1_PERIPH_GPIOB);

    io.Mode = LL_GPIO_MODE_OUTPUT;
    io.Speed = LL_GPIO_SPEED_FREQ_HIGH;
    io.OutputType = LL_GPIO_OUTPUT_PUSHPULL;
    io.Pull = LL_GPIO_PULL_NO;

    io.Pin = DRV_SCLK_PIN;  LL_GPIO_Init(DRV_SCLK_PORT, &io);
    io.Pin = DRV_SDI_PIN;   LL_GPIO_Init(DRV_SDI_PORT, &io);
    io.Pin = DRV_NSCS_PIN;  LL_GPIO_Init(DRV_NSCS_PORT, &io);
    io.Pin = DRV_EN_PIN;    LL_GPIO_Init(DRV_EN_PORT, &io);

    io.Mode = LL_GPIO_MODE_INPUT;
    io.Pull = LL_GPIO_PULL_UP;      /* SDO is open-drain */
    io.Pin = DRV_SDO_PIN;   LL_GPIO_Init(DRV_SDO_PORT, &io);

    LL_GPIO_SetOutputPin(DRV_NSCS_PORT, DRV_NSCS_PIN);   /* idle high */
}

void drv8323_init(void)
{
    drv8323_gpio_init();

    /* ENABLE high brings the device out of sleep. The datasheet requires
     * ~1 ms before the SPI interface is ready; be generous, this runs
     * once at boot. */
    LL_GPIO_SetOutputPin(DRV_EN_PORT, DRV_EN_PIN);
    for (volatile int i = 0; i < 200000; i++) { __NOP(); }

    drv8323_write(REG_DRIVER_CTRL, VAL_DRIVER_CTRL);
    drv8323_write(REG_GATE_HS,     VAL_GATE_HS);
    drv8323_write(REG_GATE_LS,     VAL_GATE_LS);
    drv8323_write(REG_OCP_CTRL,    VAL_OCP_CTRL);
    drv8323_write(REG_CSA_CTRL,    VAL_CSA_CTRL);

    /* Clear any fault latched during power-up. */
    drv8323_write(REG_DRIVER_CTRL, VAL_DRIVER_CTRL | 0x001u);  /* CLR_FLT */
}

/* Read back every control register and compare. Returns 0 on match.
 *
 * Worth calling during bring-up: a DRV8323RH accidentally fitted where an
 * RS was intended will ACK nothing and read back zeros, and this is the
 * cheapest way to find that out -- before a motor is attached. */
int drv8323_verify(void)
{
    static const uint8_t addr[5] = { REG_DRIVER_CTRL, REG_GATE_HS,
                                     REG_GATE_LS, REG_OCP_CTRL,
                                     REG_CSA_CTRL };
    static const uint16_t want[5] = { VAL_DRIVER_CTRL, VAL_GATE_HS,
                                      VAL_GATE_LS, VAL_OCP_CTRL,
                                      VAL_CSA_CTRL };
    int bad = 0;
    for (int i = 0; i < 5; i++) {
        if (drv8323_read(addr[i]) != want[i]) {
            bad++;
        }
    }
    return bad;
}

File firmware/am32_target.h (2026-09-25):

/* dshot-esc-100a -- AM32 target definition.
 *
 * Paste into AM32's Inc/targets.h and add DSHOT_ESC_100A to the Makefile
 * target list. See firmware/README.md for the rationale behind each value.
 */

#ifdef DSHOT_ESC_100A
#define FILE_NAME       "DSHOT_ESC_100A"
#define FIRMWARE_NAME   "ESC100A G071"

/* Raw TIM1 BDTR.DTG value, NOT nanoseconds.
 * TIM1 runs at 64 MHz with PSC=0 and CKD=DIV1, so t_DTS = 15.625 ns and
 * DTG <= 127 is linear:  40 * 15.625 ns = 625 ns.
 * Derivation and margin analysis: docs/shoot-through.md            */
#define DEAD_TIME       40

/* 0.25 mOhm shunt (4x 1 mOhm 2512) x 40 V/V DRV8323 CSA gain = 10 mV/A.
 * CSA is configured UNIDIRECTIONAL so zero current reads ~0 V, which is
 * what AM32 expects.                                              */
#define MILLIVOLT_PER_AMP 10
#define CURRENT_OFFSET    0

/* Bus voltage divider: 100k / 10k = 11:1  (verify scaling -- ESC-011) */
#define TARGET_VOLTAGE_DIVIDER 110

/* TIM1 CH1/2/3 + CH1N/2N/3N, COMP2 on PB7/PB3/PA2 with the virtual
 * neutral on PA3, DShot capture on PB4 via TIM3_CH1 + DMA1_CH1.     */
#define HARDWARE_GROUP_G0_A

/* CRITICAL. The 48-pin STM32G071CBT6 bonds PA9 and PA10 to dedicated
 * pins 29 and 32; pins 33/34 are PA11/PA12. AM32 remaps PA11/PA12 onto
 * PA9/PA10 by default, which is correct for 28- and 32-pin packages and
 * WRONG here -- it would drive the three high-side PWM outputs onto pads
 * this board leaves unconnected. Same approach as AIKON_04_G071.     */
#define NO_PA11_PA12_REMAP

/* PA4 = ADC_IN4 (bus voltage), PA6 = ADC_IN6 (current from DRV SOA) */
#define VOLTAGE_ADC_CHANNEL LL_ADC_CHANNEL_4
#define VOLTAGE_ADC_PIN     LL_GPIO_PIN_4
#define CURRENT_ADC_CHANNEL LL_ADC_CHANNEL_6
#define CURRENT_ADC_PIN     LL_GPIO_PIN_6

#define USE_SERIAL_TELEMETRY      /* USART1 one-wire on PB6 */
#define SIXTY_FOUR_KB_MEMORY

/* Configure the DRV8323RS over SPI at boot. Omit for an RH build --
 * that variant is configured entirely by R203-R206.                 */
#define USE_DRV8323

#endif

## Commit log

2026-09-25 12V/100A three-phase all-NMOS motor driver: schematic, docs, firmware
    A DShot-compatible drone ESC built around a DRV8323R smart gate driver
    and 12 N-channel MOSFETs (2 paralleled per switch position), controlled
    by an STM32G071CBT6 running AM32.
    Schematic is complete and verified: 160 components across 6 hierarchical
    sheets, 96 nets, ERC clean at 0 violations. PCB layout not started.
    Design decisions of note:
    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
    [01_power_in.kicad_sch, 02_gate_driver.kicad_sch, 03_power_stage.kicad_sch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]
2026-09-25 Fix power-symbol annotation: number project-wide, not per sheet
    kicad-cli has been reporting "schematic has annotation errors" since the
    first netlist export. Cause: write_sheet() numbered power symbols with a
    per-sheet enumerate index, so all six sheets restarted at #PWR0001 --
    179 placements sharing only 60 references.
    Component designators were never affected, but this still mattered:
    "Update PCB from Schematic" keys on the reference designator, so
    duplicates would have caused trouble the moment layout began.
    Power symbols now draw from one counter shared across the project, and
    PWR_FLAG annotates as #FLG per KiCad's own convention rather than #PWR.
    Result: 176 #PWR + 3 #FLG, all unique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
    [01_power_in.kicad_sch, 02_gate_driver.kicad_sch, 03_power_stage.kicad_sch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]
2026-09-25 PCB floorplan: 80x68 mm, 4-layer, all FETs on top over a tight ground plane
    Places all 160 footprints, sets the stackup and board outline, and lands
    DRC-clean at 0 violations (382 unconnected is expected -- nothing routed).
    The layer split is the whole point, and it is not the one I first
    suggested. Loop inductance is set by distance to the RETURN PLANE, not by
    how the FETs are stacked:
    high side top / low side bottom 1.60 mm 4.36 nH 13.1 V overshoot
    all FETs top, return on B.Cu 1.60 mm 4.36 nH 13.1 V
    all FETs top, In1 at 0.5 mm 0.50 mm 1.36 nH 4.1 V
    all FETs top, In1 at 0.2 mm 0.20 mm 0.54 nH 1.6 V <- this
    Splitting the half-bridge across th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
    [01_power_in.kicad_sch, 02_gate_driver.kicad_sch, 03_power_stage.kicad_sch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]
2026-09-28 Schematic edits from the GUI session, with the reset net repaired
    Sheets 02 and 04 were edited in Eeschema: wires rerouted, junctions
    added, parts moved, and four redundant GND symbols dropped from nets
    already joined by copper.
    One of those edits broke something. The reset network came adrift:
    before NRST = U401.10, J401.10, R401.2, C406.1
    after NRST = U401.10, J401.10
    Net-(C406-Pad1) = C406.1, R401.2
    R401 (10k pull-up) and C406 (100n) were still tied to each other but no
    longer to NRST, leaving the MCU reset pin with only its internal pull-up
    and no decoupling -- a spurious-reset risk on a board switching 100 A.
    ERC could not see it because both parts were stil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
    [02_gate_driver.kicad_sch, 04_mcu.kicad_sch]
